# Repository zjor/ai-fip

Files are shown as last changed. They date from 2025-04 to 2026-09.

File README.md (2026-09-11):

# AI-FIP — AI-controlled Flywheel Inverted Pendulum

A flywheel (reaction wheel) inverted pendulum stabilized by a neural network trained with deep reinforcement learning. The network knows nothing about the physics or its own "body"; it learns by trial and error in simulation how to swing up and hold the upright position, and is then transferred to a real device.

## Overview

Digital soul aka AI-FIP (flywheel inverted pendulum) — обратный маятник, реакционное колесо. Само-стабилизирующаяся система, управляемая нейронной сетью. НС обучается в виртуальном пространстве, ничего не зная про устройство механизма и аналитические законы. Методом проб и ошибок (DRL) она должна научиться сама управлять двигателем и считывать угол, чтобы удерживать вертикальное положение.

### Motivation

Это модельная задача обучения НС, ничего не знающей о природе своего тела; потом она сможет обучиться управлять телом любой сложности. Для меня — проектирование механической системы, устройства, изучение текущего состояния нейронных сетей и механизмов обучения с подкреплением.

### Goal

Сделать устройство, из которого можно будет сделать DIY-kit, записать курс, классное промо-видео, сделать стенд на фестиваль света подобный Signal, походить по школам и институтам, показывать для вдохновления будущих поколений.

### Definition of done

- DIY-kit
- YouTube promo-video
- Участие в выставках (Signal, Maker Faire)
- Попробовать разные алгоритмы стабилизации
- Статья на Хабр и на аналогичном популярном зарубежном портале
- Прочитать >3 лекций для общественности
- Записать видео-интервью

## Process

- [Current tasks](docs/project/tasks.md) — single prioritized list of unfinished work
- [Roadmap](docs/project/roadmap.md) — phases, milestones and gates
- [Progress log](docs/project/log.md) — completed work and decisions
- [Project-management process](docs/project/README.md) — ownership and update rules

## Repository map

Organized by concept. `software/` runs on a laptop, `hardware/` runs on the device.

```
docs/                  project management, physics, hardware, DRL, references
software/
  sim/                 Python dynamics (RK4), LQR and PID regulators
  rl/                  Gymnasium environment, SB3/PPO training, ONNX export, trained models
  web/                 browser demo running the exported ONNX policy
hardware/
  firmware/
    esp32-stepper/     legacy 2025 build: ESP32 + MPU6050 + stepper
    moteus-host/       2026 build: Raspberry Pi + pi3hat + moteus driver (planned)
  cad/                 mechanics (planned)
  tools/mpu-renderer/  serial → WebSocket bridge for IMU angles
```

Trained policies are produced by `software/rl` into `software/rl/models/`. Consumers copy them at build or deploy time: the web build copies the ONNX file, the device firmware will do the same.

## Documentation

- [Documentation index](docs/README.md)
- [Physics: equations of motion and controllability](docs/physics/equations-of-motion.md)
- [Physics primer](docs/physics/primer.md)
- [Hardware and motor selection criteria](docs/hardware/hardware.md)
- [BLDC motor candidates](docs/hardware/motor-candidates.md)
- [Reference papers](docs/references/README.md)

## Notebooks

- [Regular pendulum damping simulation](https://colab.research.google.com/drive/1u6tl5SG2cvKg8DLndMQ9u2ieP07KyDuc#scrollTo=PbFrm5GsAxk4)
- [Stabilizing FIP with LQR](https://colab.research.google.com/drive/1kIb0vfg7HsaBy3xPXdWx9-hCGLleFcXF#scrollTo=zqa5uH2bmCwl)

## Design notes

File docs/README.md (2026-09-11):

# Documentation

Project knowledge and process, organized by concept.

## Project management

- [Current tasks](project/tasks.md) — single prioritized list of unfinished work
- [Roadmap](project/roadmap.md) — phases, milestones and gates
- [Progress log](project/log.md) — completed work and decisions
- [Process](project/README.md) — ownership and update rules

## Physics

- [Equations of motion and controllability](physics/equations-of-motion.md) — Euler-Lagrange equations of the free and actuated FIP, linearized state-space form, controllability matrix
- [Physics primer](physics/primer.md) — torque, K_t, K_v, K_m, thermal limits, momentum capacity, swing-up, FOC, cogging
- [Phase 0 feasibility check](physics/phase-0-feasibility.md) — reproducible torque, momentum, thermal, and sensor timing pre-check
- [Motor torque estimation](physics/torque-estimation.md) — measured parameters of the 2025 stepper build and the holding-torque estimate
- [Double inverted pendulum](physics/double-pendulum.md) — Euler-Lagrange derivation for the double pendulum

## Hardware

- [Hardware](hardware/hardware.md) — parameters, motor selection criteria, moteus driver integration, legacy stepper BOM
- [BLDC motor candidates](hardware/motor-candidates.md) — 15 motors evaluated, shortlist, buy list, final choice
- [CAD specification](hardware/cad-spec.md) — wheel, rod and table-clamp stand for OpenSCAD (`hardware/cad/`): frame, parameters, parts, BOM, mass model

## Deep reinforcement learning

- [DRL and simulation learning track](drl/README.md) — ordered curriculum, mastery criteria and resources
- [DRL outline](drl/outline.md) — problem statement, glossary, model-based vs model-free
- [Modern simulation and RL stack (2026)](drl/modern-simulation-and-rl-stack-2026.md) — simulator survey, Apple Silicon strategy, policy architecture, parallel training, and sim-to-real plan

## References

- [Reference papers](references/README.md)

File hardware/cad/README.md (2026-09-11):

# Mechanics — OpenSCAD

Parametric models of the reaction-wheel pendulum: wheel, rod, table-clamp
stand. Design and rationale: [docs/hardware/cad-spec.md](../../docs/hardware/cad-spec.md).
All dimensions live in `params.scad`.

## Build

```shell
make parts      # STLs into build/
make masses     # mass, centroid, inertia per part + pendulum mass model
make check      # interference check (must print "check: no interference")
make test       # geometry tests (python3 -m unittest, drives openscad)
openscad assembly.scad   # interactive view; set angle=... in the customizer
```

Requires OpenSCAD ≥ 2026.06 (manifold backend) and Python 3.12 (stdlib only).
`make check` passes when OpenSCAD reports an empty top-level object: the
intersection of the pendulum at 0/90/180/270° with the stand and table is empty.

## Parts and print orientation

| Part | File / `part` | Qty | Mass (rendered) | Orientation | Notes |
|---|---|---:|---:|---|---|
| wheel quadrant | `wheel.scad` / `quadrant` | 4 | 27.7 g | flat, rim down (144 × 144 mm) | 0.2 mm layers, 3 perimeters, 30 % infill |
| wheel hub plate | `wheel.scad` / `hub` | 1 | 16.1 g | flat, nut pockets down | 100 % infill |
| beam | `rod.scad` / `beam` | 1 | 63.9 g | web flat (X up), diagonal on the bed (230 × 20 mm) | 4 perimeters |
| motor flange | `rod.scad` / `flange` | 1 | 41.7 g | on edge (X up), brim (135 × 20 mm) | 4 perimeters, 50 % infill |
| stand | `stand.scad` / `stand` | 1 | 151.6 g | on its side (X up) (98 × 74 mm) | 5 perimeters, 40 % infill, PETG preferred |
| pad | `stand.scad` / `pad` | 1 | 3.4 g | flat | |

`wheel.scad / bolts` is not a print: it models the eight M6 tuning bolts
(66.7 g steel) for the mass model.

## Mass model (`make masses`, 2026-09-04)

| Part | Mass g | z CoM mm |
|---|---:|---:|
| wheel plastic (4 quadrants + hub) | 127.0 | 250 |
| wheel bolts (8× M6×20 + nut) | 66.7 | 250 |
| beam | 63.9 | 36 |
| motor flange | 41.7 | 228 |
| mj5208 | 193.0 | 250 |
| moteus r4.11 + screws | 19.2 | 250 |
| 4S pack | 120.0 | 0 |
| RPi 4 + pi3hat + standoffs (estimate) | 85.0 | 0 |
| axle, collars, clamp screws (estimate) | 60.0 | 0 |
| **total** | **776 g** | l_c = 146 mm |

G = 1.11 Nm, I_p = 0.029 kg m², I_w = 0.0027 kg m². These are the
`[design]` values in `software/sim/phase0.toml`.

## BOM (hardware)

| Item | Qty |
|---|---:|
| Steel shaft Ø8 × 120 mm | 1 |
| 608ZZ bearing 8 × 22 × 7 | 2 |
| Shaft collar Ø8 | 2 |
| M3 × 8 screws + nuts (rim laps 4, hub 8, clamp 2, lap joint 2) | 16 |
| M3 × 8 countersunk (rotor) | 3 |
| M3 × 10 (stator) | 4 |
| M2.5 × 12 screws + 20 mm standoffs (RPi / pi3hat) | 4 |
| M6 × 20 bolt + nut (tuning) | 8–12 |
| M8 × 60 thumb screw + M8 nut | 1 |
| Velcro strap 12 mm | 2 |
| mjbots mj5208, moteus r4.11, pi3hat, Raspberry Pi 4 | 1 each |
| 4S LiPo, 1000 mAh preferred (1000–1300 mAh), ≥40 A continuous / ≥45C at 1000 mAh, XT30 + JST-XH 5-pin, ≤75 × 35 × 25 mm, 100–130 g | 1 |

## Project tracking

CAD and mechanical work is tracked centrally as T-002, T-003 and T-008 in
[docs/project/tasks.md](../../docs/project/tasks.md).

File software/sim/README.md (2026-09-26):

# Simulation and classical control

Python model of the flywheel inverted pendulum: RK4 integration of the equations of motion (see [docs/physics](../../docs/physics/equations-of-motion.md)) with LQR, PID and neural-network control laws for comparison.

## Run

```shell
poetry install
poetry run app
poetry run phase0
poetry run phase0-swingup --sweep [--torque-limit 0.5]
poetry run phase0-control --pessimistic --sweep
poetry run python -m unittest discover -s tests
```

`phase0` runs the analytical hardware feasibility pre-check from
[`phase0.toml`](phase0.toml) using the moteus firmware conventions (Kt = 8.27/Kv,
voltage-circle torque-speed envelope). `phase0-swingup` simulates energy-pumping
swing-up plus LQR catch with that envelope and reports the required flywheel
momentum. `phase0-control` sweeps sample rate, delay and noise for the sampled LQR.
Mechanical low/nominal/high values are planning ranges, not measurements; the
report stays `NOT READY` until a CAD mass model exists. Results and decisions:
[docs/physics/phase-0-feasibility.md](../../docs/physics/phase-0-feasibility.md).

## Learning exercises

The numbered, self-contained [MuJoCo exercises](learning/mujoco/) are kept
separate from the `app` package while sharing this Poetry environment.

## Project tracking

Simulation work is tracked centrally in
[docs/project/tasks.md](../../docs/project/tasks.md), currently T-005.A–F and
T-009–T-012.
The associated curriculum and mastery criteria are in
[docs/drl/README.md](../../docs/drl/README.md).

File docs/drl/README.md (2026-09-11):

# DRL and simulation learning track

This is the curriculum for mastering deep reinforcement learning and 3D
simulation through AI-FIP. Project progress and current learning actions are
tracked only in [project/tasks.md](../project/tasks.md); the project phases
and gates live in [project/roadmap.md](../project/roadmap.md).

Principle: learn each concept by building, explaining, and measuring it in the
project. Do not start new policy training until the honest-simulation gate is
passed with a classical controller.

## Curriculum

- **MuJoCo foundations:** understand MJCF body trees, frames, hinge joints,
  inertial parameters, actuators, sensors, timestep, integration and the Python
  stepping/viewer API.
- **Validated 3D digital twin:** construct the two-DOF pendulum and reaction
  wheel from primitive dynamic geometry; reproduce the analytical RK4 model in
  passive, constant-torque and closed-loop trajectories; add CAD meshes only as
  visual geometry.
- **Honest classical-control baseline:** model the measured motor envelope,
  current limits, friction/cogging, sensor noise, sampling and delay; demonstrate
  swing-up, LQR catch, stabilization and wheel despinning.
- **RL foundations:** be able to explain and calculate MDP transitions,
  returns, value and action-value functions, Bellman equations, policy gradients,
  actor-critic, advantage estimation/GAE and PPO clipping.
- **Gymnasium environment design:** define deployable observations and
  actions, termination versus truncation, reward components, normalization,
  deterministic seeding and vectorized evaluation around the validated model.
- **PPO baseline:** train a small 2x64 policy and compare it with LQR using
  physical metrics: success rate, angle RMS, wheel speed, saturation, current,
  energy and recovery envelope—not reward alone.
- **Robustness and sim-to-real:** train and test across measured parameter
  ranges, use held-out worst-case evaluation, compare pure PPO with residual PPO,
  export the actor and measure end-to-end latency on the target host.

## Practical MuJoCo track

The self-contained exercises live in
[`software/sim/learning/mujoco/`](../../software/sim/learning/mujoco/). Their
progression is: viewer and static geometry; free-body contact; passive hinge
pendulum; Python stepping and logging; torque actuation and feedback; simple CAD
mesh import and mass-property comparison; and finally the two-DOF pendulum and
reaction wheel.

The final model starts with primitive dynamic geometry and explicit inertial
parameters. CAD meshes can then be compared against it and used where their
added geometric detail is useful. The track is complete when free fall, a fixed
torque pulse and the same LQR controller agree with the analytical RK4 model
within explicit error bounds or documented discrepancies.

## Resources

- [MuJoCo modeling guide](https://mujoco.readthedocs.io/en/latest/modeling.html)
- [MuJoCo Python bindings](https://mujoco.readthedocs.io/en/stable/python.html)
- [PPO explanation and equations](https://spinningup.openai.com/en/latest/algorithms/ppo.html)
- [Modern simulation and RL stack for this project](modern-simulation-and-rl-stack-2026.md)
- [DRL outline and glossary](outline.md)

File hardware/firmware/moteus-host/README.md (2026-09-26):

# moteus host controller

Control loop for the 2026 build: Raspberry Pi + pi3hat (CAN-FD, IMU) commanding a moteus driver with an mjbots mj5208 motor. Python, LQR first, then the ONNX policy from `software/rl/models/`.

See [docs/hardware/hardware.md → Driver: moteus](../../../docs/hardware/hardware.md) and [docs/project/roadmap.md](../../../docs/project/roadmap.md) Phase 3. Current work is tracked in [docs/project/tasks.md](../../../docs/project/tasks.md).

## Minute clock

`minute-clock` is a small bench exercise for learning position control. An arrow
attached to the motor advances 30 degrees every 5 seconds and completes one
revolution per minute. It runs continuously until `Ctrl-C`.

Use Python 3.12+ and the official [`moteus` Python
package](https://pypi.org/project/moteus/). From this directory:

```shell
poetry install
poetry run minute-clock --calibrate
```

With `--calibrate`, the controller first enters stop mode. Rotate the arrow to
12 o'clock by hand and press Enter. The program stores that absolute encoder
angle, modulo one revolution, in `.minute-clock-zero.json`. The file is local
device state and is ignored by Git.

On later runs, omit `--calibrate`. The program loads the stored zero, moves to
the nearest equivalent 12 o'clock position, waits until the arrow settles, and
then starts the five-second ticks. Recalibrate only if the arrow moves relative
to the rotor or if you intentionally want to redefine 12 o'clock.

The program assumes controller ID 1 and lets the `moteus` package auto-detect
the connected `fdcanusb`. Run it first with the motor securely mounted, the
arrow clear of people and objects, and a way to disconnect power immediately.
The initial limits are intentionally modest: 0.10 Nm, 0.25 rev/s and
0.50 rev/s².

Positive position may look clockwise or counterclockwise depending on the side
from which the arrow is viewed and the configured motor direction. If the first
tick goes the wrong way, press `Ctrl-C` and recalibrate with the other sign:

```shell
poetry run minute-clock --calibrate --clockwise-sign -1
```

The chosen clockwise sign is stored alongside the zero position.

Useful options:

```shell
poetry run minute-clock --help
poetry run minute-clock --id 2 --max-torque 0.05
```

The command is refreshed every 20 ms and uses a 100 ms watchdog. Normal exit,
`Ctrl-C`, and Python exceptions all send `set_stop()` before the process exits.
Cut power if the host or CAN adapter itself fails; software stopping is not an
emergency stop.

## Bench characterization

The T-005.A–F bench suite stores raw runs under the ignored `logs/bench/` directory.
Tracked safety and experiment defaults are in `bench.toml`; the measurement
design and later experiments are documented in
[`docs/hardware/motor-bench-spec.md`](../../../docs/hardware/motor-bench-spec.md).

Start with the stopped-state inspection. It does not command motion:

```shell
poetry run bench inspect
```

It records five seconds of telemetry plus the complete controller configuration
and firmware identity. Review the reported voltage, temperature, home state and
fault before continuing.

The first motion experiment performs two cycles of +30°, centre, −30°, centre
at the conservative limits in `bench.toml`:

```shell
poetry run bench position-step
```

The program prints the resolved motion limits and requires typing `MOVE` before
it enables position control. Both commands always attempt `set_stop()` on exit.
Each run contains `run.json`, `controller-config.txt`, `telemetry.csv` and
`events.csv`.

After position steps pass, the low-speed friction/cogging experiment stages at
the nearest endpoint of `[-0.5, +0.5]` rev, sweeps one full revolution to the
opposite endpoint, then returns over the same positions:

```shell
poetry run bench friction
```

It takes about 100 seconds of motion at 0.02 rev/s, caps torque at 0.05 Nm, and
requires typing `SWEEP`. The arrow needs unobstructed 360° clearance. Progress is
reported every five seconds, and experiment-specific hard limits stop motion if
speed exceeds 0.35 rev/s or displacement exceeds 1.10 revolutions. The velocity
margin permits the short stick-slip releases that this experiment measures; it
does not change the commanded 0.02 rev/s trajectory. Setup samples are retained
but excluded from the forward/reverse measurement phases. Preflight reads the
moteus position bounds and verifies that both fixed sweep endpoints fit with the
configured 0.02 rev endpoint margin.

For this bench fixture, the moteus bounds are `[-1.1, +1.1]`:

```text
conf set servopos.position_min -1.1
conf set servopos.position_max 1.1
conf write
```

Restart tview after changing configuration, then close it before running
`bench` so both programs do not compete for the CAN adapter. These remain hard
controller limits; the friction command also independently stops at 1.10 rev
displacement from its recorded origin.

Analyze a completed friction run offline with:

```shell
poetry run bench analyze logs/bench/<run-id>
```

The command leaves raw files unchanged and writes `summary.json`, a
100-position-bin `friction-map.csv`, and standalone SVG plots under `plots/`.
It uses matched forward/reverse medians to estimate direction-dependent
friction and position-periodic torque, and reports the dominant spatial
harmonics. All torque outputs remain labeled as moteus model-derived estimates,
not independent torque measurements.

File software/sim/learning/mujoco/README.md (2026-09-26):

# MuJoCo learning exercises

Small, cumulative exercises for learning MuJoCo while working toward
[T-001](../../../../docs/project/tasks.md). Each numbered directory is a runnable
snapshot and should remain understandable on its own.

Assets reused by multiple exercises live in [`assets/`](assets/). Exercise MJCF
files reference that directory with paths relative to their own location, so a
mesh has one canonical copy without depending on another numbered exercise.

Run commands from `software/sim` so every exercise uses this subproject's
Poetry environment.

## Exercises

1. [`01-static-box`](01-static-box/) — load a minimal MJCF scene and explore
   the interactive viewer and camera controls.
2. [`02-free-box`](02-free-box/) — add a dynamic body and observe gravity,
   contact, free-joint state, and mouse perturbations.
3. [`03-pendulum`](03-pendulum/) — constrain a compound body to one hinge and
   explore joint axes, local coordinates, inertia, and damping.
4. [`04-periodic-kicks`](04-periodic-kicks/) — step the model from Python and
   apply periodic torque pulses through a hinge motor actuator.
5. [`05-feedback-control`](05-feedback-control/) — close the loop with a
   saturated PD controller and reject external torque disturbances near upright.
6. [`06-cad-wheel`](06-cad-wheel/) — import the Onshape reaction-wheel STL and
   compare its compiled mass properties with a same-envelope solid cylinder.
7. [`07-flywheel-pendulum`](07-flywheel-pendulum/) — assemble the passive
   flywheel pendulum with a world-fixed support, motor housing and independently
   hinged CAD wheel, without actuation or contacts.
8. [`08-actuated-wheel`](08-actuated-wheel/) — swing up with energy shaping,
   catch and despin with LQR, then reject seeded random force pulses applied
   perpendicular to the rod; compare free fall, fixed-pulse and LQR trajectories
   with an analytical RK4 model.

Add later exercises as new numbered directories instead of rewriting earlier
ones. Keep observations that are specific to an exercise in that exercise's
README. Project task state remains in `docs/project/tasks.md`.

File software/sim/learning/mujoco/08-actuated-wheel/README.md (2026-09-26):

# 08 — Swing-up, LQR catch, and random kicks

This exercise controls the complete motion in one simulation. It starts just
beside the downward equilibrium, pumps pendulum energy through the reaction
wheel, hands over to LQR near upright, and then applies random external pushes
to test disturbance recovery. Torque is recalculated before every 2 ms MuJoCo
step.

From `software/sim`, run the deterministic 18-second scenario:

```shell
poetry run python learning/mujoco/08-actuated-wheel/check_model.py
```

On macOS, view it at half real-time speed:

```shell
poetry run mjpython learning/mujoco/08-actuated-wheel/view.py
```

Press **Backspace** to restart near the hanging position. Controller mode
changes and kick events are printed in the terminal.

Compare the same model against an analytical RK4 integrator:

```shell
poetry run python learning/mujoco/08-actuated-wheel/compare_rk4.py
```

## Viewer plots

Four synchronized plots are stacked from the rendering viewport's top-right:

1. requested control `u`, before torque limiting;
2. absolute wheel angular velocity;
3. actual motor torque after limiting;
4. wrapped rod angle in degrees, with zero at upright.

Their compact titles are `u`, `ω`, `τ`, and `θ`. Each panel is now composed from
two independent pixel-space components: a 54 px header and a chart body. The
header renders DejaVu Sans with 14 px left and top padding. The requested panel
size is 576 × 390 px and all panels shrink identically only when the viewport
cannot fit the stack.

The chart body uses a fixed 72 px scale gutter and fixed frame coordinates.
Only the mapping from telemetry values to pixels changes when the Y range
changes; header, gutter, frame width, and frame height do not move. Rendering
the panels directly as images avoids `MjvFigure`'s data-dependent tick layout.

All plots use a rolling time axis from −10 s to 0, where zero is the newest
sample. Each vertical range follows its visible signal and adds 20% of the data
span on both sides; a small minimum range keeps constant signals readable. Grid
lines are hidden. Resetting the simulation also clears all plot history.

## Ideal actuator

The wheel hinge has a direct-drive torque source limited to the current mj5208
peak-torque assumption:

```xml
<motor name="wheel-torque" joint="wheel-hinge" gear="1"
       ctrllimited="true" ctrlrange="-1.7 1.7"/>
```

This is not yet an electrical motor model: there is no torque-speed curve,
current loop, command delay, or battery model. During swing-up, software applies
a lower ±0.5 N·m cap to avoid needlessly accumulating wheel momentum.

## State and LQR

The reduced controller state is

```text
x = [pendulum angle, pendulum rate, absolute wheel rate]
```

The hinge reports wheel speed relative to the carrier, so

```text
absolute wheel rate = pivot rate + wheel-hinge rate
```

`controller.py` finite-differences MuJoCo's continuous accelerations around the
motionless upright equilibrium to obtain `A` and `B`. It solves the continuous
Riccati equation with the Phase 0 costs:

```text
Q = diag(120, 2, 0.015)
R = 0.8
u_lqr = clip(-K x, -1.7, +1.7)
```

Penalizing absolute wheel rate makes LQR despin the wheel instead of balancing
with steadily accumulating momentum. Relative wheel angle is omitted because
the axially symmetric wheel has no preferred rotor angle.

## Swing-up and catch

With angle zero at upright and ±π at hanging, the pendulum energy relative to
upright is

```text
E = 0.5 I theta_rate² + G (cos(theta) - 1)
```

The controller derives `I` and `G` from the compiled MuJoCo model. While energy
is below the upright target it commands

```text
u_swing = clip(-k (-E) theta_rate, -0.5, +0.5)
```

Motor torque acts oppositely on the carrier, hence the minus sign. The controller
switches to LQR inside a 30° catch cone when the energy error is within 5% of
the hanging-to-upright energy difference. If it leaves 45°, it falls back to
swing-up mode.

## Random perpendicular kicks

After the first LQR catch, `disturbance.py` schedules seeded random pushes every
2.5–3.5 seconds, following an initial 1.0–1.5 second delay. Each push lasts
40 ms and has a random sign and magnitude from 2–4 N.

The force is applied at the wheel centre with `mujoco.mj_applyFT`. Its world
direction is the pendulum body's local X axis, while the rod lies on local Z;
those axes remain perpendicular as the pendulum rotates. This models an actual
lateral poke rather than injecting torque through the motor actuator. Seed 7
makes checks and viewer resets reproducible.

## Analytical RK4 comparison

`rk4.py` uses the reduced state `x = [θ, θ̇, ω]`, where `ω` is absolute wheel
speed. For applied wheel torque `u`, carrier inertia `I`, axial wheel inertia
`J`, gravity coefficient `G`, pivot damping `b_p` and relative wheel-hinge
damping `b_w`, its equations are:

```text
τ_w = u − b_w (ω − θ̇)
θ̈ = (G sin θ − b_p θ̇ − τ_w) / I
ω̇ = τ_w / J
```

The constants come from the compiled `scene.xml` mass matrix, gravity bias at
90°, and joint damping. For the current scene they are `I = 0.028399817 kg·m²`,
`J = 0.001464308 kg·m²`, `G = 1.134974359 N·m`, `b_p = 0.0002 N·m·s/rad`, and
`b_w = 0.005 N·m·s/rad`. This avoids a second, drifting set of physical inputs
while keeping the differential equations and RK4 step independent of MuJoCo's
dynamics solver. Torque is held constant over each 2 ms step. LQR uses the same
gain but computes its own torque from each model's state, with ±1.7 N·m clipping.

`compare_rk4.py` checks free fall from 10° for 0.7 s, a +0.2 N·m pulse for
0.1 s from upright followed by 0.4 s of coasting, and LQR from 5° for 2 s.
The maximum trajectory errors must stay below these limits:

| MuJoCo integrator | Scenario | Angle | Pivot rate | Wheel rate | Torque |
|---|---|---:|---:|---:|---:|
| Euler (scene default) | Free fall | 0.8° | 0.02 rad/s | 0.05 rad/s | 0 N·m |
| Euler (scene default) | Fixed pulse | 0.2° | 0.02 rad/s | 0.05 rad/s | 0 N·m |
| Euler (scene default) | LQR | 0.2° | 0.02 rad/s | 0.2 rad/s | 0.02 N·m |
| RK4 | Each scenario | 0.00001° | 0.00001 rad/s | 0.00001 rad/s | 0.00001 N·m |

The Euler bounds cover integration error at the scene's 2 ms step. In the
current comparison, the largest Euler angle error is 0.68834° during free fall;
the largest LQR wheel-rate error is 0.15936 rad/s. Switching MuJoCo to RK4 for
the same checks reduces all printed differences below 0.00000001 in their
respective units. The runner executes both integrators and exits nonzero if a
bound is exceeded. Angle differences are wrapped to ±π before comparison. The
RK4 result checks the equations, parameter extraction, actuation signs and
state mapping; the Euler result bounds the numerical
discrepancy of the scene as normally run. Swing-up and kick recovery remain
separate scenarios for later honest-model validation.

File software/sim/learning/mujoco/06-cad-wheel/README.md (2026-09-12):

# 06 — CAD reaction wheel

This exercise imports a binary STL exported from Onshape, verifies its scale
and orientation, and compares its compiled inertia with a same-mass solid
cylinder occupying the same outer envelope.

The STL format does not store units. The source coordinates are millimetres,
so the MJCF mesh asset applies `scale="0.001 0.001 0.001"`. The wheel's axle is
the source X axis. The mesh is closed and centred at its origin. Its canonical
copy is [`../assets/wheel.stl`](../assets/wheel.stl), shared with later
exercises instead of duplicated in each directory.

From `software/sim`, inspect the compiled model without opening a GUI:

```shell
poetry run python learning/mujoco/06-cad-wheel/inspect_model.py
```

Open the scene with:

```shell
poetry run python learning/mujoco/06-cad-wheel/view.py
```

The scene keeps the wheel fixed and disables contacts. This separates mesh
import, scaling and rendering from joints and collision behavior. The next
exercise can reuse the mesh as visual geometry while giving the reaction wheel
a hinge and deliberately selected collision and inertial properties.

## Mass and inertia assumptions

The mesh geom uses a PLA density of 1250 kg/m³. MuJoCo computes exact volume
integrals over the closed mesh because the asset specifies `inertia="exact"`.
This is useful for checking the CAD export, but the physical model should
eventually use the measured mass and inertia of the printed wheel plus bolts,
rotor and fasteners.

The `polished-metal` material changes only rendering. In MuJoCo's classic
viewer, a cool-grey color with high `specular` and `shininess` produces the
metallic appearance; it does not change the geom's PLA density or inertia.

The comparison cylinder has the mesh's mass, outer radius and thickness. It is
not a collision approximation: a solid cylinder fills the wheel's holes and
therefore distributes mass differently. Mesh collision would likewise use a
convex representation rather than reproduce every opening, so the imported
mesh is visual-only in this exercise.

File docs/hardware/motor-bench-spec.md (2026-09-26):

# mj5208 + moteus r4.11 bench characterization

## 1. Purpose

This bench suite turns T-005.A–F into reproducible measurements for the Phase 0
feasibility model and the later honest MuJoCo actuator model. It is not a single
maximum-power test. Work progresses from low-energy checks to mechanically
contained tests, and every run preserves raw commands, responses, configuration
and operator notes.

The required outputs are:

- command-to-motion delay and position/velocity tracking;
- low-speed friction and cogging versus rotor position, before and after moteus
  anti-cogging compensation;
- an independently measured torque constant from a lever arm and scale/load
  cell;
- coast-down loss versus speed with a known attached inertia;
- reachable torque versus speed and bus voltage;
- continuous stall torque versus motor winding temperature;
- explicit uncertainty and provenance for every value transferred into the
  simulation.

## 2. Operator workflow

The suite will expose one `bench` command from
`hardware/firmware/moteus-host`:

```shell
poetry run bench inspect
poetry run bench position-step
poetry run bench friction
poetry run bench coast-down
poetry run bench torque-constant
poetry run bench torque-speed
poetry run bench thermal-hold
poetry run bench analyze logs/bench/<run-id>
```

Each motion command prints the resolved limits and setup requirements, performs
a stopped-state preflight, asks for explicit operator confirmation, records one
run directory, and sends `set_stop()` on normal exit, fault, timeout or
`Ctrl-C`. A physical power disconnect remains mandatory; software stop is not
an emergency stop.

The friction experiment stages at the nearer of −0.5 or +0.5 rev, then measures
one full mechanical revolution to the opposite endpoint and back. Thus both
directional datasets cover identical rotor positions within `[-0.5, +0.5]`;
setup data is retained under a separate phase. Preflight validates the captured
moteus `servopos.position_min/max`, rejects a starting position outside them,
and requires 0.02 rev clearance between each sweep endpoint and either finite
bound. The bench program never rewrites persistent controller configuration.

Tests are introduced in three safety tiers:

| Tier | Experiments | Mechanical requirement |
|---|---|---|
| A | `inspect`, `position-step`, very slow `friction` | Current desk stand; light arrow; clear workspace |
| B | `coast-down`, inertia/acceleration sweeps, moderate-speed tests | Balanced retained rotor/flywheel and a guard; no arrow |
| C | `torque-constant`, `torque-speed`, `thermal-hold` | Purpose-built restraint/load fixture, independent force or temperature instrumentation, supervised run |

The clock is not reused for Tier B or C: its arrow is unsuitable for meaningful
speed, torque or thermal characterization.

## 3. Telemetry record

The target acquisition rate is 200 Hz for motion tests and 20 Hz for slow
thermal tests. Every row in `telemetry.csv` contains values as received or sent;
derived quantities belong in analysis outputs.

### Host and run state

| Field | Unit | Purpose |
|---|---:|---|
| `sample` | count | Detect missing or duplicated rows |
| `host_time_s` | s | Monotonic time from the first command |
| `scheduled_time_s` | s | Intended sample time for jitter analysis |
| `request_time_s`, `response_time_s` | s | CAN round-trip and timing jitter |
| `experiment_phase` | text | Preflight, settle, sweep, coast, cooldown, etc. |

### Commanded values

| Field | Unit |
|---|---:|
| `command_mode` | text |
| `command_position_rev` | rev |
| `command_velocity_rev_s` | rev/s |
| `feedforward_torque_nm` | N·m |
| `maximum_torque_nm` | N·m |
| `velocity_limit_rev_s` | rev/s |
| `accel_limit_rev_s2` | rev/s² |
| `watchdog_timeout_s` | s |

Unused command fields are empty, not silently replaced with zero.

### moteus response

| Field | Unit | Notes |
|---|---:|---|
| `mode`, `fault` | enum | Always recorded; any fault ends motion |
| `position_rev` | rev | Output position |
| `velocity_rev_s` | rev/s | Output velocity |
| `torque_nm` | N·m | moteus estimate, not an independent torque sensor |
| `q_current_a`, `d_current_a` | A | Measured phase-current components |
| `bus_voltage_v` | V | Controller input voltage |
| `electrical_power_w` | W | Positive into motor, negative into DC bus |
| `controller_temperature_c` | °C | r4.11 board temperature |
| `motor_temperature_c` | °C | Valid only with a configured motor thermistor |
| `home_state`, `trajectory_complete` | enum/bool | Encoder reference and trajectory state |

The logger requests floating-point position, velocity and torque plus sufficient
resolution for current, voltage, power and temperature. The exact query format
is stored in run metadata.

### Independent and manual observations

`events.csv` records timestamped facts not supplied by moteus:

- applied force or load-cell reading and lever-arm length;
- external winding/case temperature and ambient temperature;
- physical stop, contact, noise or vibration;
- operator abort and reason;
- configuration changes such as enabling anti-cogging.

If an external sensor later gains a programmatic interface, its samples receive
their own raw file and clock description rather than being disguised as moteus
telemetry.

## 4. Run metadata and derived results

`run.json` is written before motion and finalized after stop. It records:

- run ID, wall-clock start/end and exact CLI invocation;
- experiment name and all resolved limits/setpoints;
- motor, controller, CAN adapter, supply and mechanical-fixture identifiers;
- arrow/flywheel/load configuration, mass and known inertia;
- ambient conditions, cooling state and external instruments;
- Python and `moteus` versions, Git revision and dirty state;
- controller ID, firmware information and query resolution;
- result (`completed`, `aborted`, `fault`, `timeout`) and reason.

`controller-config.txt` is a read-only configuration snapshot captured before
the run. This is essential because PID gains, motor `Kv`, current limits,
position scaling, anti-cogging and thermal settings change the meaning of the
telemetry.

Offline analysis writes `summary.json` and plots, never modifies raw files.
Typical derived signals are RPM, position/velocity error, angular acceleration,
mechanical power $\tau\omega$, estimated copper loss, latency percentiles,
temperature rise and fitted friction/cogging curves. The analysis must label
reported torque as model-derived and use external force data for the torque
constant result.

## 5. Repository and data layout

```text
hardware/firmware/moteus-host/
  pyproject.toml
  bench.toml                    tracked conservative defaults and stop limits
  moteus_host/
    clock.py
    bench/
      cli.py                    command selection and operator interaction
      servo.py                  moteus query format and command cycle
      recorder.py               run metadata, CSV and event writing
      safety.py                 preflight, limits, fault/timeout stop path
      experiments/
        inspect.py
        position_step.py
        friction.py
        coast_down.py
        torque_constant.py
        torque_speed.py
        thermal_hold.py
      analysis/
        summarize.py
        plots.py
  tests/
    test_clock.py
    bench/
  logs/                         ignored; never committed
    bench/
      20260920T143012Z_position-step/
        run.json
        controller-config.txt
        telemetry.csv
        events.csv
        summary.json            generated by `bench analyze`
        friction-map.csv        matched directional position bins
        plots/                  generated PNG/SVG files
```

CSV plus JSON is preferred initially: the data volume is small, files are easy
to inspect, and no dataframe dependency is required in the hardware control
path. A column/schema version in `run.json` allows a later Parquet export
without changing the raw acquisition format.

## 6. Experiment sequence and gates

1. **Inspect and idle baseline.** Confirm identity, firmware, home state, bus
   voltage, zero current, temperatures and configuration snapshot without
   motion.
2. **Position steps.** Reuse the safe clock-scale motion to validate timestamps,
   watchdog behavior, tracking, repeatability and latency.
3. **Slow bidirectional friction/cogging.** Traverse several revolutions in both
   directions at very low speed. Fit repeatable torque versus wrapped position
   and direction. Back up configuration before changing anti-cogging settings.
4. **Independent torque constant.** Use a measured lever arm and scale/load
   cell at several low currents in both directions. moteus-reported torque is a
   comparison channel, not the reference measurement.
5. **Coast-down and acceleration.** Only with a known, retained inertia and
   guard. Estimate velocity-dependent losses and check torque-to-acceleration.
6. **Torque-speed envelope.** Sweep only bus voltages and speeds relevant to
   the 12.0–16.8 V design range. A credible torque-at-speed result requires a
   known inertia or external load; an unloaded speed sweep alone measures only
   the no-load boundary.
7. **Thermal hold.** Requires a motor thermistor or external temperature probe
   and a restraint rated for the commanded torque. Increase current/torque in
   conservative plateaus with configured absolute temperature, temperature-rise,
   temperature-rate, board-temperature, voltage and time stop conditions.
8. **Publish.** Transfer fitted values with uncertainty and run IDs into
   `docs/physics/phase-0-feasibility.md` and `software/sim/phase0.toml`; keep raw
   logs local and uncommitted.

Tier B starts only after the retained rotating assembly and guard exist.
Tier C starts only after its fixture and independent instrumentation are
documented and checked.

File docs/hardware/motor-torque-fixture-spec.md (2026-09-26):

# MJ5208 static torque fixture

## 1. Purpose

This fixture independently measures the mj5208 torque constant for T-005.C. A
rigid lever attached to the rotor presses vertically on a compression scale
while moteus commands short Q-axis current plateaus. The scale is the force
reference; moteus-reported torque is recorded only for comparison.

The first test is deliberately limited to ±8 A and approximately ±0.20 Nm. It
does not characterize peak torque, continuous thermal torque or torque at speed.

## 2. Measurement principle

```text
                         motor axis
                             O
                             │
    left contact ●───────────┼───────────● right contact
                 <--- 100.0 mm --->
                                                ↓ force
                                          ┌───────────┐
                                          │   scale   │
                                          └───────────┘
```

Use a balanced crossbar with a contact point on each side. Put the scale under
the contact loaded by the commanded torque direction; move it to the other side
for the opposite direction. The force must be perpendicular to the lever.

For effective radius $r$ and zero-corrected scale reading $m$:

$$
\tau = m g r
$$

With $r = 0.1000$ m and the reading expressed in grams:

$$
\tau[\mathrm{N\,m}] = m[\mathrm{g}] \times 0.000980665
$$

The fitted model is:

$$
\tau = K_t I_q + b
$$

where $I_q$ is measured Q-axis current, not merely its requested value. The
slope is the independently measured torque constant. The intercept contains
scale preload, zero error, residual cogging and fixture bias.

## 3. Mechanical design

### 3.1 Lever

- balanced metal crossbar, nominally 200 mm between contact centerlines;
- effective radius from the motor axis to each force line: **100.0 mm**;
- measure each radius after assembly to ±0.2 mm or better;
- aluminium flat bar is preferred; a printed lever is not the measurement
  reference because creep and bending add avoidable error;
- rigid hub using the mj5208 rotor M3 pattern, with no angular play;
- an adjustable rounded metal contact at each end, such as an M4 screw with a
  ball or acorn end;
- bar horizontal at the measurement point, so the vertical scale force is
  perpendicular to the radius.

The effective radius is the perpendicular distance from the motor axis to the
vertical force line. It is not automatically the physical bar length if the bar
or contact is angled.

### 3.2 Load path

- bolt the motor stator bracket and scale base to the same stiff baseplate;
- do not hold the motor, lever or scale by hand;
- constrain the scale so it cannot slide sideways;
- include a secondary hard stop just beyond normal scale deflection;
- add a loose guard or restraint that catches the lever if contact is lost;
- leave the unloaded end of the crossbar clear.

The scale is a measurement instrument, not the only structural restraint.

### 3.3 Scale

The available compression scale is rated to 3 kg with 0.1 g display resolution.
At 100 mm its nominal torque increment is 0.0000981 Nm. This is more than
sufficient; calibration accuracy, repeatability, force alignment and lever
radius dominate the uncertainty.

Check the scale before use with at least two known masses spanning roughly
0.2–1.0 kg. Record displayed resolution, repeatability, auto-zero behavior,
auto-off behavior and whether the reading is stable under a constant load.

## 4. Range

| Scale reading | Torque at 100.0 mm |
|---:|---:|
| 10 g | 0.00981 Nm |
| 100 g | 0.0981 Nm |
| 200 g | 0.196 Nm |
| 500 g | 0.490 Nm |
| 1000 g | 0.981 Nm |
| 1733 g | 1.70 Nm |

The scale can nominally contain the published 1.7 Nm motor peak at this radius,
but scale capacity alone does not qualify the fixture for a peak-torque test.
The hub, bracket, baseplate, contact, restraint, supply and thermal limits would
all require a separate Tier-C review.

## 5. Initial test protocol

### 5.1 Preconditions

- crossbar and hub inspected and fasteners marked against loosening;
- motor stator, scale and hard stop fixed to the common baseplate;
- contact radius measured and recorded for each side;
- scale checked with known masses, zeroed and prevented from auto-off;
- no hands or loose objects in the lever envelope;
- physical power disconnect immediately accessible;
- controller stopped, fault 0, bus voltage and temperature in limits;
- software watchdog and unconditional `set_stop()` path verified with a fake
  controller before the physical run.

### 5.2 Current plateaus

Use commanded Q-current plateaus of:

```text
0, 1, 2, 4, 6, 8 A
```

Run positive and negative directions separately, placing the scale beneath the
appropriate compression contact. Use measured `q_current_a` in analysis. Start
with 2–3 second plateaus and stop between plateaus. Repeat every nonzero point
three times. Abort on motion, loss of contact, unstable load, unexpected noise,
fault, voltage violation, current violation or temperature violation.

At the planning value $K_t \approx 0.025$ Nm/A, 8 A should produce about 0.20
Nm or 204 g at 100 mm. Do not raise the current range merely because the scale
has unused capacity.

### 5.3 Manual scale readings

The first version uses manual readings. The host must continue refreshing the
watchdog while current is active; a blocking terminal prompt must never pause
motor commands. Prefer this sequence:

1. run a fixed-duration plateau while recording moteus telemetry;
2. give the operator an audible/terminal timing cue;
3. stop the controller;
4. enter the observed stable or held scale reading in grams;
5. record side, current sign, radius, repetition and operator note in
   `events.csv`.

A camera recording of the scale display is useful evidence when the scale lacks
a data interface.

## 6. Planned software

`poetry run bench torque-constant` will reuse the recorder and safety layer. It
must:

- require a fixture-specific confirmation phrase;
- command current directly rather than request torque from the configured motor
  model;
- keep D-axis current at zero;
- refresh a 100 ms watchdog throughout every plateau;
- enforce the tracked 8 A initial phase-current limit;
- record requested and measured Q/D current, position, velocity, reported
  torque, bus voltage, power, controller temperature, fault and timing;
- stop between plateaus and on normal exit, fault, timeout or `Ctrl-C`;
- record manually entered scale readings and the measured contact radius;
- refuse higher-current profiles until the fixture receives a separate review.

Offline analysis will calculate torque for every reading, fit $K_t$ and an
intercept for each direction, compare slopes, report residuals and uncertainty,
and compare physical torque with moteus-reported torque.

## 7. Uncertainty and acceptance

At minimum, propagate:

- scale calibration and repeatability;
- scale resolution;
- left/right effective-radius measurement;
- lever non-perpendicularity, using the measured sine correction if needed;
- contact-position repeatability;
- measured-current variation during the reading window;
- regression residuals and positive/negative slope disagreement.

Accept the initial result when:

- force is monotonic with measured current in both directions;
- repeated readings at each plateau agree within a declared tolerance;
- positive and negative fitted $|K_t|$ values agree within 5%, or the asymmetry
  is investigated;
- the fit includes at least four nonzero current magnitudes per direction;
- no fixture motion, controller fault or safety-limit violation occurred;
- raw telemetry, events, controller configuration, dimensions and scale checks
  are preserved with the run ID.

## 8. Safety boundary

The initial fixture is approved only for short plateaus up to 8 A. It is not yet
approved for the published 1.7 Nm peak, continuous stall/thermal testing or
rotating torque-speed work. Those tests require a reviewed restraint, motor
temperature instrumentation and, for rotating tests, a retained balanced rotor
and guard.

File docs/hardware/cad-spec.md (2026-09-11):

# CAD specification — wheel, rod, stand (OpenSCAD)

Status: approved design, 2026-09-04. Source of truth for `hardware/cad/`.
Dimensions here are defaults; `hardware/cad/params.scad` is the single place
they live in code. When the two disagree, fix the one that is wrong and say so
in [project/log.md](../project/log.md).

## 1. Purpose and inputs

Printable mechanics for the 2026 build: a reaction-wheel pendulum on a
table-edge stand, driven by an mjbots mj5208 + moteus r4.11, sensed by the IMU
on a pi3hat riding on the pendulum, powered by a 4S pack on the pivot axis.

Decisions this spec implements (see [project/log.md](../project/log.md), 04.09.2026):

| Decision | Value |
|---|---|
| Pivot topology | rotating 8 mm axle clamped in the rod, two 608 bearings in the stand |
| Stand | C-clamp on the desk edge, cantilever bearing arm, axle perpendicular to the edge |
| Fabrication | FDM, PLA/PETG 1.25 g/cm³, bed 220 × 220 mm, parts > bed are segmented |
| Wheel | Ø280, four identical quadrants + hub plate, printed rim provides most of the inertia, M6 bolts for tuning |
| Angle sensor | IMU on the pendulum; no encoder on the stand (axle end kept free for one) |
| Electronics on the pendulum | 4S pack and RPi + pi3hat centred on the axle |
| Targets from Phase 0 | I_w ≈ 0.003 kg·m², rod 250 mm axle-to-motor-axis, G within the 0.97–1.34 Nm planning range (section 5 estimates 1.19) |

Verified motor mounting data (mjbots product page and blog, 2026-09-04):
mj5208 Ø63 × 25 mm, 193 g; rotor 3× M3 on a Ø17 bolt circle plus 2× M3 at
12 mm spacing; stator 4× M3 at 25 mm spacing plus 3× M2.5 at 32 mm. The exact
hole geometry (square vs. circle, depth, shaft protrusion) is **to verify**
against the mjbots 2D drawing before the first motor-flange print; it is
isolated in one parameter block and one part for that reason.

## 2. Coordinate frame

Right-handed, millimetres.

- Origin: axle centre, on the rod's mid-plane.
- **Z** up along the rod when the pendulum is upright.
- **Y** along the axle, positive away from the table edge.
- **X** along the table edge.

The pendulum rotates about Y. The stand occupies Y < 0 (bearing arm) and
Y ≪ 0 (clamp on the table). The axle sits `axle_height` above the table top so
the bearing arm clears the surface; the table top is the box X ∈ ℝ,
Y ≤ −`axle_overhang`, Z ∈ [−`axle_height` − `table_thickness`, −`axle_height`].

## 3. Parameters (`params.scad`)

| Name | Default | Meaning |
|---|---:|---|
| `bed` | 220 | printable square, mm; parts longer than `bed·√2 − 15` are split |
| `rho_pla` | 1.25e-3 | g/mm³ |
| `rod_len` | 250 | axle axis to motor axis |
| `wheel_d` | 280 | rim outer diameter |
| `rim_radial` | 8 | rim radial thickness (sized for inertia per gram, not stiffness; 2026-09-04) |
| `rim_axial` | 8 | rim axial width |
| `spokes` | 8 | two per quadrant |
| `spoke_w`, `spoke_t` | 4, 8 | spoke section (tangential × axial) |
| `hub_d`, `hub_t` | 60, 5 | hub plate and quadrant flange |
| `pocket_n`, `pocket_bolt` | 16, M6 | tuning holes, every 22.5° starting at 11.25°, axial through the rim, plain (nut and head clamp the rim faces) |
| `motor_d`, `motor_len` | 63, 25 | mj5208 |
| `rotor_bc_d`, `rotor_n` | 17, 3 | rotor pattern, M3 |
| `stator_pitch`, `stator_n` | 25, 4 | stator pattern, M3, square — **to verify** |
| `axle_d`, `axle_len` | 8, 120 | steel shaft |
| `bearing` | 8 × 22 × 7 | 608 |
| `bearing_spacing` | 40 | between bearing centres |
| `axle_overhang` | 60 | table edge to rod mid-plane |
| `axle_height` | 30 | table top to axle centre |
| `table_thickness` | 18–40 | clamp range |
| `battery` | 75 × 35 × 25 | 4S 1000 mAh class, on the table side of the rod |
| `hat_holes` | 58 × 49, M2.5 | RPi/pi3hat pattern, on the outer side of the rod |
| `beam_w`, `beam_h`, `flange_t`, `web_t` | 20, 20, 3, 3 | rod I-beam section |
| `clearance` | 0.3 | print fit for lap joints and pockets |
| `M3`, `M2.5`, `M6`, `M8` | 3.4, 2.8, 6.4, 8.4 | through-hole diameters |

## 4. Parts

### 4.1 Wheel (`wheel.scad`)

Five prints: four identical **quadrants** and one **hub plate**.

- Quadrant: a 90° rim arc (r from `wheel_d/2 − rim_radial` to `wheel_d/2`,
  width `rim_axial`), two spokes at 22.5° and 67.5°, and a 90° sector of the
  hub flange (r ≤ `hub_d/2`, thickness `hub_t`). Rim ends carry a half-lap
  joint (5 mm long, half the rim width) with one M3 through-hole; flange
  sector has two M3 holes on a Ø45 circle matching the hub plate.
- Hub plate: Ø`hub_d` × `hub_t` disc with the rotor pattern (3× M3 on Ø17,
  countersunk from the motor side), a Ø10 centre bore for the rotor boss,
  and 8× M3 on Ø45 for the quadrants.
- Tuning holes: `pocket_n` axial through-holes Ø`M6` in the rim at
  r = `wheel_d/2 − rim_radial/2`, every 22.5° starting at 11.25° so no hole
  lands on a lap seam or a spoke; no recess (the M6 nut overhangs the 8 mm rim
  by 1 mm per side, which is harmless). Bolts are always fitted in
  diametrically opposite pairs; the standard fit is 8 bolts every 45°.
- Lightening: none beyond the spoke design; the quadrant's rim and spokes are
  already the minimum structure.

Estimated: rim 68 g, spokes 31 g, flanges + hub plate 34 g → **~135 g
plastic, I_w ≈ 0.0015 kg·m² empty**; each M6 × 20 bolt + nut (≈ 10 g) at
r = 136 mm adds ≈ 0.000185 kg·m². Eight bolts (80 g) reach 0.0030, so the
standard wheel is ≈ 215 g. The rim was deliberately thinned from 12 × 10 mm:
plastic at the rim gives 0.0185 kg·m² per kg, a bolt at the rim 0.0185 too,
but spokes and hub give almost nothing, so the structure is kept minimal and
the inertia is bought with bolts where it can be tuned.

The wheel bolts to the rotor. The rotor's second pattern (2× M3 at 12 mm) is
left unused.

### 4.2 Rod: beam (`rod.scad`, module `beam`)

One print, laid diagonally on the bed. From the axle clamp at Z = 0 to the
lap joint ending at Z = `rod_len − 60` (bed fit).

- Section: I-beam, `beam_w` × `beam_h`, flanges `flange_t`, web `web_t`.
- Web cutouts: elliptical holes, 8 × 30 mm, centred at Z = 65, 100, 135;
  none in the tray zone or near joints.
- Axle clamp at Z = 0: a split clamp block 30 × 30 × 20 mm around Ø`axle_d`,
  slot 1.5 mm, two M3 clamping screws across the slot. The axle is also
  cross-drilled and pinned optionally (hole provided, Ø2).
- Tray zone Z ∈ [−45, 45] (the battery is centred on the axle):
  - table side (−Y): a shelf 80 × 40 mm with two 12 mm strap slots for the
    4S pack; pack outer face at Y = −(beam_h/2 + 25).
  - outer side (+Y): four M2.5 bosses on the 58 × 49 HAT pattern, 6 mm high,
    HAT long axis along Z, bosses at Z = ±29 so the board is centred on the
    axle.
- Lap joint at the top: the beam ends in a half-thickness tongue 40 mm long
  with two M3 through-holes 25 mm apart, mating the flange plate's groove.

Estimated 60 g.

### 4.3 Rod: motor flange (`rod.scad`, module `motor_flange`)

One print. A plate Ø70 × 6 mm carrying the stator pattern (4× M3 on the
`stator_pitch` square, counterbored), a Ø12 centre hole for the rotor
shaft/magnet side, and a 40 mm groove continuing the I-beam down to overlap
the beam's tongue (two M3 through-holes). The motor sits on the +Y face; the
wheel therefore spins on the outer side, away from the table.

Estimated 25 g. Reprint this part alone once the stator pattern is verified.

### 4.4 Stand (`stand.scad`)

One print (two if `bed` forbids), PLA at ≥ 4 perimeters, solid where loaded.

- C-clamp: throat depth 60 mm, opening 18–40 mm, jaw 40 mm wide; the fixed
  jaw is the top, the moving jaw is an M8 thumb screw through a printed
  M8 nut pocket in the lower jaw, with a 25 mm pad. Clamp body wall 8 mm.
- Cantilever bearing arm: rises `axle_height` from the clamp's top jaw and
  extends along +Y so that the two 608 pockets (Ø22 +0.2, 7 deep, with a 1 mm
  shoulder and an inner Ø17 relief) sit at Y = −(`axle_overhang` − 10) − 40
  and Y = −(`axle_overhang` − 10), i.e. at −90 and −50 with the defaults. The
  arm is a 40 × 40 box beam with 6 mm walls and diagonal ribs, its underside
  ≥ 5 mm above the table top; the axle passes through both bearings with a
  printed spacer between and a shaft collar outboard of each bearing.
- The axle end at −Y protrudes 8 mm past the inner bearing and is left free
  (future encoder magnet).
- Clearance requirements: rod mid-plane at Y = 0 is `axle_overhang` from the
  table edge; the battery's outer face at Y = −35 leaves ≥ 20 mm to the edge;
  the wheel and motor are at Y > 0 and clear everything.

Estimated 180 g. Weight does not matter here; stiffness does.

### 4.5 Axle and hardware (BOM in `hardware/cad/README.md`)

| Item | Qty |
|---|---:|
| Steel shaft Ø8 × 120 mm (h6) | 1 |
| 608ZZ bearing 8 × 22 × 7 | 2 |
| Shaft collar Ø8 | 2 |
| M3 × 8 screws (wheel joints, clamp, lap joint) | 24 |
| M3 × 8 countersunk (rotor to hub plate) | 3 |
| M3 × 10 (stator to flange) | 4 |
| M2.5 × 12 + standoffs (RPi/pi3hat) | 4 |
| M6 × 20 bolt + nut (tuning) | 8–12 |
| M8 × 60 thumb screw + nut | 1 |
| Velcro strap 12 mm | 2 |

## 5. Mass model and feedback to Phase 0

`make masses` computes each printed part's volume, centroid and inertia from
its STL and combines them with catalogue hardware masses. Rendered on
2026-09-04 (`hardware/cad/README.md` has the per-part table):

| Part | Mass | z of CoM | Contribution to G (Nm) |
|---|---:|---:|---:|
| wheel plastic + 8 tuning bolts | 194 g | 250 | 0.48 |
| mj5208 + r4.11 + screws | 212 g | 250 | 0.52 |
| motor flange | 42 g | 228 | 0.09 |
| beam | 64 g | 36 | 0.02 |
| axle, collars, clamp screws (estimate) | 60 g | 0 | 0 |
| 4S pack | 120 g | 0 | 0 |
| RPi 4 + pi3hat + standoffs (estimate) | 85 g | 0 | 0 |
| **total** | **0.776 kg** | l_c = 0.146 m | **G = 1.11 Nm** |

I_p = 0.029 kg m² (beam as a slender rod, everything else as point masses),
I_w = 0.0027 kg m² with 8 bolts (10 bolts give 0.0030). This sits between the
Phase 0 nominal (0.97 Nm) and pessimistic (1.34 Nm) corners, where the r4.11
has ≥ 3.7× margin at 20° and passes torque-capped swing-up at every point. The
uncapped direct lift at 12 V reaches 71–79 % of no-load wheel speed at
I_w 0.0027, above the 70 % limit: fit 10 bolts (0.0030) or cap swing-up torque
at 0.5 Nm in software. Two levers if the printed parts
come out heavier: shorten `rod_len` (G ∝ rod length), or use an RPi Zero 2 W.
These numbers are the `[design]` block of `software/sim/phase0.toml`
(nominal, −10 % / +10 %); `poetry run phase0 && poetry run phase0-swingup
--sweep` must still pass after any change.

## 6. Build and checks (`Makefile`)

- `make parts`: renders `wheel_quadrant.stl`, `wheel_hub.stl`, `beam.stl`,
  `motor_flange.stl`, `stand.stl` headlessly
  (`openscad --backend=manifold -o <out> -D part="<name>" <file>`).
- `make masses`: renders each part and computes volume, mass, centroid and
  moment of inertia from the STL with `tools/stl_props.py`;
  `tools/mass_model.py` combines them with the hardware masses into m_t, l_c,
  I_p and I_w.
- `make check`: renders `check.scad`, which computes the intersection of the
  pendulum assembly at 0°, 90°, 180°, 270° with the stand and with the table
  box. The Makefile fails if the resulting STL contains any facet.
- `make view`: renders `assembly.stl` for visual inspection; the assembly
  file also shows the pendulum at a parametric angle.

Each part also fits the bed: `lib.scad` asserts the part's bounding box
against `bed` (diagonal allowed) at render time.

## 7. Files

```
hardware/cad/
  params.scad     all dimensions, materials, hardware sizes
  lib.scad        report(), screw holes, bed assertion, hex nut pocket
  wheel.scad      quadrant, hub_plate; part selector
  rod.scad        beam, motor_flange; part selector
  stand.scad      clamp + bearing arm
  assembly.scad   everything placed, pendulum angle parameter
  check.scad      interference checks
  Makefile        parts, masses, check, view
  README.md       how to build, BOM, print settings, project-task links
```

## 8. Out of scope

Wiring, the CAN cable routing on the rod, the power switch, a battery
charger port, cable strain relief, and an encoder seat. These are Phase 1
detailing after the first print reveals what is missing.

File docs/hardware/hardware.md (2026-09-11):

# Hardware

##### Parameters
| Name | Value | Units |
| --- | ----- | ----- |
| Plastic density | 1.25  | g/cm³ |
| Wheel mass | | |
| Wheel inertia | | |
| Pendulum mass | | |
| Pendulum inertia | | |
| Mass of equipment  | | |
| Mass of a motor | | |
| Motor torque | | |
| Pendulum length, L | 0.25  | m |
| Wheel radius, R | 0.125 | m |

## Motor selection criteria

*Approved 2026-08-10. Scope: desktop DIY-kit scale, onboard battery (3S–4S), direct-drive BLDC + FOC, motor budget ≤ €120. Parametric — numbers are current estimates (m_t ≈ 0.55 kg incl. battery, l_c ≈ 0.18 m); Phase 0 of the [roadmap](../project/roadmap.md) iterates them.*

### Operating regimes

Each regime produces a distinct constraint:

- **Balance hold** — near-zero speed, rapid small torque reversals. Stall regime: pure I²R heating with no airflow; cogging torque directly pollutes control.
- **Disturbance recovery** — peak torque at low speed; sets the max recoverable angle.
- **Swing-up** — sustained torque while the wheel spins up; back-EMF eats torque as speed grows. Sets speed headroom and momentum capacity — likely the binding constraint for low-Kv gimbal motors.

### Hard criteria (pass/fail)

| # | Criterion | Formula | First estimate |
|---|---|---|---|
| 1 | Peak torque | τ_peak ≥ k·m_t·g·l_c·sin θ_max, k = 1.5–2, θ_max = 20° | ≥ 0.5–0.65 Nm |
| 2 | Torque reachable at bus voltage | K_t·min(V_bus/R_ph, I_driver) ≥ τ_peak | kills most high-R gimbal motors — check per candidate |
| 3 | Momentum capacity | I_wheel·ω_noload ≥ H_swingup (from honest sim), ω_noload = K_v·V_bus | TBD in Phase 0 — likely binding |
| 4 | Thermal continuous torque | ≥ ~0.3·τ_peak sustained at stall, no airflow | ≥ ~0.2 Nm |
| 5 | Motor mass | ≤ 0.2 kg (feeds back into m_t) | 5208-class ok |
| 6 | Smoothness | low cogging (≤ a few % of τ_peak), FOC-friendly PMSM | gimbal-class winding |
| 7 | Encoder | integrated magnetic encoder or exposed rear shaft for diametric magnet | AS5048A / MT6701 |
| 8 | Mechanical | rotor flange/holes to mount the wheel; Ø40–60 mm | |
| 9 | Price / sourcing | ≤ €120, EU/Ali availability (kit replicability) | T-Motor GB, iPower GM |

### Optimization objective, ranked

1. **Specific torque τ/m_motor (Nm/kg)** — the feasibility lever: motor mass raises its own torque requirement.
2. **K_v sweet spot** — high enough for momentum capacity at 11–15 V, low enough that τ_peak fits the driver current limit. Roughly K_v 30–100, K_t 0.1–0.3 Nm/A, R_ph ≲ 6 Ω.
3. **Cogging + friction minimal** — control quality around zero speed.
4. **Price, then documented torque/speed curve** — the real advantage of the €120 class over AliExpress.

No composite score — rank candidates by specific torque among those passing all nine gates.

**Amendment 2026-08-10:** the I_driver = 5 A assumption (SimpleFOC-class boards) was dropped in favor of moteus-class drivers (20–100 A peak). With the current limit gone, gate 2 stops favoring high-K_t gimbal windings: for the same stator, K_t ∝ turns and R ∝ turns², so the winding-independent figure of merit is the **motor constant K_m = K_t/√R** (torque per √watt of copper loss), and the practical limits become driver current and thermal (I²R at stall), not bus voltage. This reopened low-K_t robot motors → decision: mjbots mj5208 + moteus (see [motor-candidates.md](motor-candidates.md)).

## Driver: moteus — интеграция (researched 2026-08-11)

**Компания:** mjbots Robotic Systems LLC — США, Cambridge, Massachusetts; основана в 2019 Josh Pieper. Прошивка и софт открыты (Apache 2.0, [github.com/mjbots/moteus](https://github.com/mjbots/moteus)). ⚠️ На сайте: "shipping holiday — new orders ship August 17, 2026".

**Интерфейс:** CAN-FD 5 Mbps (разъём JST PH-3). Два протокола: register protocol (команды управления: position/velocity/torque + телеметрия) и diagnostic protocol (конфигурация, консоль). Классический CAN не подходит — нужны CAN-FD кадры; при длинной/шумной шине BRS отключается → 1 Mbps.

**Языки/библиотеки (в репо `lib/`):** Python (`pip install moteus`, asyncio API: `Controller.set_position()/set_stop()/query()`, `make_*` + `transport.cycle()` для мультимоторных шин), C++, Rust. GUI: `pip install moteus-gui` → `tview` (телеметрия, плоты, конфиг, REPL).

**Подключение к хосту (варианты):**
1. **ПК (dev): [fdcanusb](https://mjbots.com/products/fdcanusb) / mjcanfd-usb-1x** — USB→CAN-FD адаптер, Linux/Win/mac. Python-библиотека находит его автоматически (`transport=None`).
2. **Raspberry Pi (боевой контур): [pi3hat](https://mjbots.com/products/mjbots-pi3hat-r4-5)** — шляпа с CAN-FD + IMU на борту (IMU пригодится для угла маятника!); контур управления ≥1 kHz, `pip install moteus-pi3hat`.
3. **MCU (ESP32/STM32):** ESP32 имеет только классический CAN (TWAI) — нужен внешний SPI-контроллер CAN-FD (MCP2518FD) либо STM32G4 с FDCAN. Сложнее; для старта не рекомендуется.

**Электрика (из [electrical-setup](https://github.com/mjbots/moteus/blob/main/docs/guides/electrical-setup.md)):** питание XT30, полярность не защищена; hot-plug запрещён (inrush в конденсаторы — подключить всё, потом подавать питание / использовать mjpower-ss); фазы A/B/C припаиваются в любом порядке; терминатор CAN на конце шины.

**Рекомендуемый стек для маятника:** mj5208 + **moteus r4.11** (решение 2026-09-04: c1 даёт лишь 0.50 Nm peak и 0.125 Nm continuous без обдува — не проходит 20° и continuous-gate; см. [phase-0-feasibility.md](../physics/phase-0-feasibility.md)) + Raspberry Pi с pi3hat (CAN-FD и IMU одним устройством) — Python-контур для LQR/NN; fdcanusb для настольной отладки и tview.

**Константы moteus (проверено по прошивке, 2026-09-04):** K_t = 8.27/Kv (не 60/(2π·Kv)); фазное напряжение ограничено ≈0.4·V_bus, поэтому холостая скорость ≈ 0.7·Kv·V_bus (mj5208 при 12 V: 2740 rpm). Питание: 4S LiPo на оси вращения маятника.

### Battery requirement

Обычный **4S LiPo**: 14.8 V nominal / 16.8 V full, 1000–1300 mAh, разряд не менее 40 A continuous (для 1000 mAh — рейтинг ≥45C), силовой разъём XT30 и балансировочный JST-XH 5-pin. Ограничения CAD: не более 75 × 35 × 25 mm, целевая масса 100–130 g; предпочтительный вариант — 1000 mAh. Нужен 4S balance charger со storage mode. При торможении moteus возвращает энергию в DC bus, поэтому рекуперативные тесты нельзя начинать с полностью заряженной батареей.

## Legacy — 2025 stepper plan

##### Stepper motor torque
Considering [Nema 17](https://www.gme.cz/v/1500760/nema-17-dc-motor-krokovy-5v-2a-pro-tiskarny)
Current: <2A
Static torque: ~0.2...0.4 Nm (0,48Nm)
Dimensions: 42,3 x 42,3 x 39,8 mm
Mass: 0.22 ... 0.5 (depending on the model)
`Model: 17HS4401`
`1.7A, 0.42Nm`

###### BOM
| Name | Qty | Price | URL | Description |
| --- | --- | ----- | --- | --- |
| Bearing housing | 3 | | [ali](https://www.aliexpress.com/item/4000909587517.html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) | Used for holding a shaft |
| ESP32 DevkitC | 1 | | | |
| A4988 | 1 | | [hookup instruction](https://lastminuteengineers.com/a4988-stepper-motor-driver-arduino-tutorial/) | Stepper motor driver |
| L7805CV | 1 | | [mouser.com](https://cz.mouser.com/ProductDetail/STMicroelectronics/L7805CV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) | 5V voltage regulator |
| MPU9250 | 1 | | | Accel unit |

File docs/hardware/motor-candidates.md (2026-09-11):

# BLDC motor candidates

Researched 2026-08-10 against the [selection criteria](hardware.md#motor-selection-criteria) (15 motors evaluated from 22 scouted; sources: manufacturer datasheets, shop listings, SimpleFOC community builds).

**Method note:** reachable torque computed as τ = K_t · min(V_bus / R_terminal, 5 A) using **terminal (line-to-line) resistance** — two phases conduct, so per-phase R understates the limit ~2×. Several manufacturer "peak torque" claims cross-check against this formula (GL40 KV70: 0.15 × 3.29 A = 0.49 ≈ published 0.5 Nm peak).

## Verdict table (ranked)

| Motor | K_t, Nm/A | R_ll, Ω | τ @ 4S, Nm | ω_nl @ 4S, rpm | Mass, g | Ø, mm | Price EU | Encoder | Verdict |
|---|---|---|---|---|---|---|---|---|---|
| **CubeMars GL40 KV70** | 0.15 | 4.5 | **0.49** | 940 | 107 | 46.5 | €85 / €110 w-enc | factory variant | **Shortlist #1** — only full-caps pass, but τ ceiling = the floor |
| **iPower GM5208-24** | ~0.40 (derived) | 13.7 (11.1 meas.) | 0.43–0.60 | ~330 | 204 | 59.5 | €52 | add AS5048A in bore | **Shortlist #2** — cheap; swing-up momentum risk (Kv≈21) |
| **CubeMars G60 KV55** | 0.205 | 1.2 | **1.03** (5 A cap) | 814 | 226 | 69 | €132 | encoder bundle avail | **Stretch** — best performer; breaks mass/Ø/price caps ~10–15% |
| CubeMars GL60 KV25 | 0.45 | 5.5 | 1.21 | 318 | 230 | 69 | €132 | bundle avail | Stretch — big torque, low speed ceiling (momentum risk) |
| CubeMars GL40 II KV82.5 | 0.11 | 3.0 | 0.54 | 1221 | 125 | 46.1 | €154 | integrated 14-bit | Over budget; integrated CAN driver, not for external FOC |
| CubeMars GL60 II KV28 | 0.34 | 5.8 | 0.87 | 414 | 276 | 70.5 | €185 | none | Fail: mass+price (best-in-class cogging 1.5 cN·m) |
| iPower GM4108H-120T | ~0.1 (load spec) | 11.1 | ~0.2 | ~400 | 124 | 47 | €40 | AS5048A variant | Fail: torque — canonical SimpleFOC pendulum motor, too weak for our m·g·l |
| iPower GM6208-150T | ~0.87 (derived) | 32 | 0.40 | 163 | 249 | 69.5 | €85 w-enc | AS5048A variant | Fail: torque at 4S + size |
| Maxon EC 45 flat 60W (591477) | 0.036 | 0.94 | 0.18 (5 A cap) | 3922 | 113 | 43.5 | ~€150+? | Halls | Fail: needs ~26 A for its 0.9 Nm stall — wrong class for 5 A/4S |
| Eaglepower LA8308 90KV | 0.106 | 0.186 (unclear) | 0.53 | 1332 | 336 | 92 | €60 | none | Fail: 336 g / Ø92 blow the envelope |
| GBM2804H-100T / MKS YT2804 | ~0.064 | 10 | ~0.08 | 2220 | 50 | 35 | €16 | AS5600 integrated | Fail: torque ~6× short — light stick-pendulums only |
| MotorGo 3506 | unpublished | 9.5 (phase) | ~0.1–0.15 est | ? | 75 | 40 | €28 | magnet built-in | Fail: torque; camera-gimbal class |
| Nidec 24H677 | n/a (integrated driver) | n/a | 0.025 rated | n/a | ? | ? | €6 | FG speed only | Fail: no FOC access, 20× under torque floor — remrc-cube baseline only |

GL40 KV70 listed twice by scouts (two variants of same motor) — merged above. 4S numbers assume 14.8 V and a ≥5 A FOC driver.

## Shortlist notes

### 1. CubeMars GL40 KV70 — the in-budget pick
- Rated 0.25 Nm / peak 0.5 Nm @ 3.3 A; K_v–K_t self-consistent (63.5 rpm/V ↔ 0.15 Nm/A). 14 pole pairs, IP45, low-cogging gimbal winding, 8 mm hollow shaft.
- **On 3S only ~0.37 Nm → must run 4S.** Even then τ_max ≈ 0.5 Nm sits exactly at the criteria floor (k=1.5, θ_max=20°) — Phase 0 must confirm with real m_t·l_c whether the margin holds, or θ_max shrinks to ~15°.
- Its 107 g helps its own cause: lightest of the passing motors, lowers m_t.
- Encoder variant sold (model/IC undisclosed — verify interface before buying); base variant takes a diametric magnet in the 8 mm bore.
- Wheel mount: 4×M3 rotor-side per reseller; bolt circle unpublished — **check CubeMars STEP/2D drawing before designing the flywheel**.
- EU: OpenELAB Munich €84.65 / €109.95 w-encoder. Sources: [cubemars.com](https://www.cubemars.com/product/gl40-kv70-gimbal-motor.html), [store.cubemars.com](https://store.cubemars.com/products/gl40-kv70), [OpenELAB](https://openelab.io/products/cubemars-gl40-kv70-bldc-gimbal)

### 2. iPower GM5208-24 — the cheap proven-ish option
- K_t ~0.40–0.46 Nm/A **derived from Kv, not published**; SimpleFOC community measured lower R than spec (5.57 Ω used as phase value in their build) → τ @ 4S realistically 0.5–0.6 Nm.
- 204 g — exactly at the mass cap; Kv ≈ 21 → ω_nl @ 4S only ~330 rpm → smallest momentum ceiling of the shortlist; swing-up feasibility must be checked in Phase 0 sim first.
- A SimpleFOC user ran FOC current mode on it but called torque "unsatisfying" at a 1.2 A current limit — our 5 A budget is 4× that, so not disqualifying.
- No encoder; standard fix is AS5048A + diametric magnet on a plug in the 12.6 mm bore.
- EU: iflight-rc.eu €51.90 in stock. Sources: [iflight-rc.eu](https://iflight-rc.eu/en/products/ipower-gm5208-24-gimbal-motor), [SimpleFOC thread](https://community.simplefoc.com/t/optimizing-the-capabilities-of-ipower-gm5208-with-foc-current/2068)

### 3. CubeMars G60 KV55 — the stretch pick
- R_ll only 1.2 Ω → driver-limited: full 5 A × 0.205 = **1.03 Nm even on 3S** — 2× margin over the floor, and ω_nl @ 4S ≈ 814 rpm gives the best torque×momentum combination of the list.
- Costs the envelope: 226 g (+13% over cap), Ø69 mm, €132 (+10% over budget). The extra 120 g of motor raises required torque by ~0.1–0.15 Nm — still ~2× margin. If Phase 0 shows GL40's 0.5 Nm is not enough, this is the answer.
- Naming trap: store.cubemars.com "G60 KV55" page shows 472 g / Ø77 — that's an older/larger variant or shipping weight; series table + OpenELAB say 226 g. Verify at order time.
- EU: OpenELAB €131.95. Sources: [cubemars.com G60](https://www.cubemars.com/goods-955-G60.html), [OpenELAB](https://openelab.io/products/cubemars-g60-kv25-kv55-bldc)

## Buy list — top 7 (researched 2026-08-10)

Torque floor relaxed to **≥ 0.45 Nm @ 4S** after the battery-at-pivot decision (see log). τ@4S = K_t·min(14.8/R_ll, 5 A). Prices approximate, EUR, before shipping unless noted. Second sweep added 8 new candidates from SteadyWin / MyActuator (LK-TECH); all verified against manufacturer datasheets.

**Motors #6–7 are integrated-driver servos**: factory FOC driver + encoder onboard, commanded over CAN/RS485 — no SimpleFOC stage to build, but our own FOC code is bypassed. Architecture decision for Phase 1.

| # | Motor | τ@4S, Nm | ω_nl@4S, rpm | Mass, g | Encoder | Best buy | Price |
|---|---|---|---|---|---|---|---|
| 1 | CubeMars GL40 KV70 (w/ encoder) | 0.49 | 940 | 107 | factory (type undisclosed) | [OpenELAB EU — in stock](https://openelab.io/products/cubemars-gl40-kv70-bldc-gimbal) | €109.95 (+€19.95 ship); base €84.65; [CubeMars CN $97.99](https://store.cubemars.com/products/gl40-kv70) |
| 2 | iPower GM5208-24 | 0.5–0.6 | ~330 | 204 | none → AS5048A in bore | [iFlight EU (Austria) — in stock](https://iflight-rc.eu/en-us/products/ipower-gm5208-24-gimbal-motor) | €51.90; [iFlight CN $42.99](https://shop.iflight.com/ipower-motor-gm5208-24-brushless-gimbal-motor-pro1347) |
| 3 | CubeMars G60 KV55 | 1.03 (5 A cap) | 814 | 226 | none | [OpenELAB EU — in stock](https://openelab.io/products/cubemars-g60-kv25-kv55-bldc) | €131.95 (+€19.95); [CubeMars CN $108.99](https://store.cubemars.com/products/g60) — confirm KV55/226 g variant, store header wrongly says 472 g |
| 4 | SteadyWin GB6010-11 (w/ AS5048A) | 0.68–0.88 | ~237 | 241 (270 w-enc) | factory AS5048A or AS5600 | [SteadyWin CN — in stock](https://steadywin-motor.com/products/small-brushless-servo-motor-hollow-flat-gimbal-servo-drone-gimbal-camera-motor-8) | $39.50 w-enc (~€36); [AIFITLAB $36](https://aifitlab.com/products/steadywin-gb6010-motor) |
| 5 | CubeMars GL60 KV25 | 1.21 | 318 | 230 | optional variant | [DigiKey — 18 pcs, ~3 days](https://www.digikey.com/en/products/detail/cubemars/GL-60/16705299) | $108.99; [Oz Robotics w-enc $138.99](https://ozrobotics.com/shop/cubemars-gl60-kv25-bldc-gimbal-motor-with-encoder/); OpenELAB sold out |
| 6 | MyActuator RMD-L-5015 35T CAN (= LK-TECH MF5015 V2) | 0.82 | 636 (datasheet Kv 43; SMC title says 16KV — verify winding) | 174 | 14-bit integrated + CAN driver | [SMC Powers CN — in stock](https://shop.smc-powers.com/MF5015-CAN-16KV.html) | $84 (~€72); [RobotShop EU — restocking](https://eu.robotshop.com/products/myactuator-rmd-l-5015-35t-brushless-dc-motor-can); [datasheet](https://www.myactuator.com/l-5015-details) |
| 7 | MyActuator RMD-L-4015 20T CAN | 0.52 | 932 | 120 | 18-bit integrated + CAN driver | [SMC Powers CN — in stock](https://shop.smc-powers.com/MF4015-CAN-V2.html) | $77.50 (~€67) — confirm 20T winding with seller; [RCDrone $109 — sold out](https://rcdrone.top/products/myactuator-l-4015-20t-direct-drive-servo-motor-24v-0-49n-m-peak-torque-18-bit-encoder-can-rs485-for-robotics-and-drones) |

### Late addition — the winner: mjbots mj5208 + moteus (2026-08-10)

Dropping the SimpleFOC/5 A driver assumption reopened the low-K_t/high-current class ([details in log](../project/log.md)):

| Motor | K_t, Nm/A | τ peak | ω_nl@4S | Mass | Price | Buy |
|---|---|---|---|---|---|---|
| **mjbots mj5208** (Kv 330) | 0.025 (moteus 8.27/Kv; 0.027 at measured Kv 304) | 0.50 Nm w/ moteus-c1 (20 A); **1.7 Nm** w/ r4.11 (62–68 A) | 2740 rpm @ 12 V, 3380 @ 14.8 V under moteus (voltage circle) | 193 g | $74 (657 in stock) | [mjbots.com](https://mjbots.com/products/mj5208) |

*Corrected 2026-09-04: K_t and no-load speed now follow the moteus firmware conventions; the earlier 0.029 Nm/A, 0.58 Nm and 4900 rpm were the hobby formulas. Measured R_ph 0.047 Ω, L 28.6 µH, 14 poles. Driver decision: r4.11 — see [phase-0-feasibility.md](../physics/phase-0-feasibility.md).*

Pair with [moteus-c1](https://mjbots.com/products/moteus-c1) ($69, 20 A peak / 5 A cont bare, onboard encoder, CAN-FD, 8.9 g) or [moteus r4.11](https://mjbots.com/products/moteus-r4-11) ($94, 100 A peak, 12/32 A cont). Devkit-matched pair: board mounts over the rotor's rear diametric magnet. Bundle ≈ $143 — same as GL40+driver, with 1.2–3.5× the torque and no momentum ceiling. Caveats: US shipping + ~25–30% CZ VAT/duty; Ø63 mm; cogging character unverified (not a gimbal winding — check mjbots anti-cogging before ordering). GL40 KV70 stays as EU-stock fallback.

Honorable mentions (pass torque, fail mass/price): SteadyWin [DD7010-2](https://shop.smc-powers.com/DD7010-2-RS485-CAN.html) (1.10 Nm, 570 rpm, 261 g, $81.80 — don't confuse with -11 variant), LKMTECH [MHF6015-V3](http://shop.smc-powers.com/MHF6015-RS485.html) (1.30 Nm, 252 g, $135), CubeMars GL60 II KV28 (€144+, 276 g).

**Swing-up note:** motors with ω_nl ≲ 350 rpm (#2, #4, #5) have a small momentum ceiling — treat as balance-first unless Phase 0 shows a heavy rim closes the gap. #1, #3, #6, #7 have real speed headroom.

**Buying caveats:** SMC Powers (LK-TECH/MyActuator factory outlet) has an expired TLS certificate — content verified, order with that caveat or prefer RobotShop EU when restocked. AliExpress listings exist for most of these but pages didn't render for verification.

## Implications for Phase 0

1. **4S is effectively mandatory** — every shortlist motor loses 25% torque on 3S and GL40 drops below the floor.
2. **The market has a gap exactly at our spec**: in-budget gimbal motors top out at ~0.5 Nm reachable. Phase 0 feasibility math (real m_t, l_c) decides between "GL40 is enough", "pay/weigh up for G60 KV55", or "shrink the pendulum".
3. **Momentum capacity check** (criterion 3) is now concrete: compute H_swingup and compare against I_wheel × ω_nl for GL40 (940 rpm) vs GM5208 (330 rpm) — likely disqualifies GM5208 for swing-up.
4. Driver must deliver ≥5 A FOC (rules out SimpleFOC Shield v1-class 2 A boards; B-G431B-ESC1 or SimpleFOC PowerShield class needed) — feeds the Phase 1 driver decision.

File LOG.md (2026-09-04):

# Log

**04.09.2026 (4) — заказ mjbots: план и открытые вопросы на следующую сессию**
- **Рекомендация: заказывать мотор + драйвер сейчас.** Roadmap Phase 2 формально запрещает покупку железа до прохождения честной симуляции, но sampled-LQR с шумом, задержкой и реальной огибающей момент/скорость уже проходит (`phase0-control`), а два оставшихся входа Phase 2 — тепловой предел mj5208 и cogging — измеряются только на реальном моторе. Трактовка: kit = измерительный инструмент для закрытия Phase 0/2, а не прыжок через gate. **Печать механики — держать** до проверки паттерна статора по чертежу mjbots
- **Что заказывать** (цены с сайта mjbots, 04.09.2026):
  - [moteus r4.11 developer kit](https://mjbots.com/products/moteus-r4-11-developer-kit) — $219: mj5208 + r4.11 + кронштейн контроллер→мотор + БП 24 V 5 A + mjcanfd-usb-1x + STM32-программатор + разъёмы XT30/CAN + магнит энкодера. Отдельно мотор ($74) + r4.11 ($94) = $168 без кабелей, кронштейна и USB-CAN — kit выгоднее
  - [pi3hat r4.5](https://mjbots.com/products/mjbots-pi3hat-r4-5) — $149: IMU 1 kHz + 5× CAN-FD, хост для маятника. **Только для Raspberry Pi 4B / 3B+, Pi 5 НЕ поддерживается.** Для стендовых тестов не нужен (хватает USB-CAN из kit)
  - Итого $368 + доставка + ~25–30 % НДС/пошлина CZ ≈ €420–450 (оценка, не котировка)
- **Не блокирует заказ:** cogging — в moteus есть компенсация с прошивки 2022-07-11 (правки в 2024-05-20, прошивка 1.0.0 — май 2026), эффективность на mj5208 измерить на стенде; ток батареи — 1.7 Nm ≈ 65 A фазного тока, но на стопе это ~300 W → ~20 A от 4S, пакета 1000 mAh 30C достаточно
- **Вопросы, решить в следующей сессии:**
  1. Есть ли Raspberry Pi 4B или 3B+? Если только Pi 5 — pi3hat отложить, хост выбрать позже (варианты: RPi 4 + pi3hat; или другой хост + внешний IMU/энкодер)
  2. Заказывать pi3hat вместе с kit (одна доставка/растаможка) или отдельно после стендовых тестов?
  3. Согласен ли с трактовкой roadmap выше (kit до Phase 2 gate)? Если да — отметить в ROADMAP Phase 1 строку мотора как «заказано» при размещении заказа
  4. Паттерн статора mj5208: открыть 2D-чертёж с страницы продукта (Google Drive), проставить `stator_pitch`/геометрию в `hardware/cad/params.scad`, перепечатать только `motor_flange`
  5. Подстройка инерции: 8 болтов M6 (I_w 0.0027) + программный лимит момента при swing-up ≤0.5 Nm, или 10 болтов (0.0030) без лимита
- **Не из mjbots:** 4S LiPo 1000 mAh ≥30C, RPi 4B, вал Ø8×120, 2× 608ZZ, 2 стопорных кольца Ø8, метизы M3/M2.5/M6/M8 — см. BOM в [hardware/cad/README.md](hardware/cad/README.md)

**04.09.2026 (3)**
- **CAD-спецификация утверждена** ([cad-spec.md](docs/hardware/cad-spec.md)): вращающаяся ось Ø8 в двух 608-подшипниках стойки (A), стойка — струбцина на край стола с консольной подшипниковой балкой (C), ось перпендикулярна краю; угол — IMU pi3hat на маятнике; батарея 4S и RPi на оси; FDM, стол 220 мм
- колесо Ø280 из 4 одинаковых сегментов + ступица; обод 8×8 мм, 8 спиц 4×8, 16 отверстий под болты M6 для подстройки инерции (обод тонкий намеренно: пластик на ободе и болт на ободе дают одинаковую инерцию на грамм, спицы и ступица — почти ничего). По рендеру: пластик 127 g, I_w 0.0027 kg·m² с 8 болтами (0.0030 с 10)
- OpenSCAD-модели в `hardware/cad/` (`make parts|masses|check|test`): `stl_props.py` считает объём/центроид/инерцию из STL (проверено на кубе и цилиндре), 20 тестов на массы, габариты и посадку на стол печати, проверка пересечений маятника со стойкой и столом на 0/90/180/270°
- массовая модель из CAD → `phase0.toml`: m_t 0.776 kg, l_c 0.146 m, G 1.11 Nm, I_p 0.029, I_w 0.0027 (между nominal и pessimistic Phase 0). Peak/continuous и swing-up с ограничением ≤0.5 Nm проходят (24/24); прямой подъём на 1.7 Nm при 12 V раскручивает колесо до 71–79 % холостой скорости при I_w 0.0027 → 10 болтов (0.0030) или программный лимит момента. Тест `test_nominal_gravity_coefficient…` в `software/sim` переведён на CAD-значения
- открыто перед печатью: паттерн статора mj5208 (принят квадрат 25 мм, проверить по чертежу mjbots), массы RPi+pi3hat и осевой фурнитуры — оценки

**04.09.2026 (3)**
- **решение: обучение будет выполняться на Apple Silicon**; CUDA-only стек не является допустимой локальной зависимостью
- сохранён обзор современного стека симуляции и DRL → [modern-simulation-and-rl-stack-2026.md](docs/drl/modern-simulation-and-rl-stack-2026.md)
- основная рекомендация: сохранить аналитический RK4 как проверяемый oracle, построить честный 3D digital twin в MuJoCo, сначала проверить CPU MuJoCo + Gymnasium/PPO; MJX-JAX CPU/experimental Metal и Genesis Metal сравнить отдельным benchmark до выбора ускоренного backend
- нейросетевая гипотеза: маленький actor MLP 2x64, затем frame stacking/GRU только при необходимости; asymmetric critic с simulator-only параметрами; сравнить LQR+energy shaping, pure PPO и residual PPO

**04.09.2026 (2)**
- **решения:** swing-up обязателен; устройство должно держать «тычок пальцем» (θ_target = 10°, preferred 20°), сильнее — падение, флип и раскачка; механика проектируется с нуля; батарея 4S на движущейся части
- **решение: драйвер = moteus r4.11** ($94, 100 A peak / 12 A cont, 14.2 g). c1 проходит только peak-gate на 10° (2.2×), на 20° — 1.09× FAIL, continuous 0.125 Nm FAIL без обдува. r4.11: 7.3× / 3.7×, continuous 0.30 Nm, ограничен уже мотором (1.7 Nm при 62–68 A) → [phase-0-feasibility.md](docs/physics/phase-0-feasibility.md)
- **поправка K_t:** прошивка moteus считает K_t = (3/2)(1/√3)(60/2π)/Kv ≈ 8.27/Kv, а не 60/(2π·Kv). Для mj5208 (Kv 330) K_t = 0.0251 Nm/A (было 0.029, −15 %); измеренный Kv devkit-мотора 304 → 0.0272. Peak c1 = 0.50 Nm (было 0.58). Измеренные R_ph = 0.047 Ω, L = 28.6 µH, 14 полюсов (mjbots blog 2025-04-24)
- **поправка скорости:** moteus ограничивает фазное напряжение до ≈0.4·V_bus (voltage circle с margin 0.15), холостая скорость при 12 V — 2740 rpm, при 14.8 V — 3380 rpm, а не 4900 rpm по правилу Kv·V. Колено 1.7 Nm у r4.11 при 12 V — уже на 830 rpm
- **swing-up (`poetry run phase0-swingup --sweep`):** требуемый момент импульса H = I_w·ω_max не зависит от I_w: 0.19–0.28 Nms при раскачке с ограничением ≤0.5 Nm (1–2 качания, 1.1–1.3 s), 0.44 Nms при прямом подъёме на 1.7 Nm (0.3–0.4 s). Окно: I_w ≥ 0.0014 (раскачка) / 0.0022 kg·m² (прямой подъём) при 12 V; рекомендация I_w ≈ 0.003 kg·m² (колесо 2025 г. с 0.0008 не проходит). RMS ток при раскачке 5–11 A ~1 s — термически несущественно
- **батарея на оси вращения:** на верхнем конце (0.25 m) пакет 120 g даёт +30 % к G, моменту и энергии swing-up при неизменной постоянной времени; вариант — чуть ниже оси как противовес
- **тепловая модель мотора (не измерено):** P = 1.5·I²·R, R_th 3–6 K/W, ΔT 60 K → 12–17 A → 0.30–0.42 Nm continuous; совпадает с 12 A bare-рейтингом r4.11. Проверка на стенде — Phase 1
- ROADMAP Phase 0: torque budget посчитан (пункт 2 закрыт); gate в целом NOT READY — нет CAD-модели масс, теплового теста, cogging, выбора сенсора
- новое в `software/sim`: `app/phase0_swingup.py` (energy pumping + LQR catch с реальной огибающей момент/скорость), `phase0.toml` с provenance по блокам, 15 тестов

**04.09.2026**
- добавлен воспроизводимый Phase 0 pre-check (`software/sim/phase0.toml`, `poetry run phase0`) и документ с формулами/критериями (`docs/physics/phase-0-feasibility.md`); все неподтверждённые значения явно оставлены planning ranges или `UNKNOWN`
- предварительный результат на pessimistic corner (0.65 kg, CoM 0.21 m, $\theta=20°$): mj5208+c1 даёт только 1.26× peak margin → FAIL относительно порога 1.5×; mj5208+r4.11 даёт 3.71× → PASS по peak torque, но это не финальный выбор
- Phase 0 пока `NOT READY`: нужны CAD/BOM mass model, continuous thermal torque и cogging mj5208, $H_{swingup}$ из constrained simulation, validation выбранного sensor/estimator
- добавлен provisional sampled-LQR sensor sweep с saturation, torque-speed envelope и command delay; на pessimistic planning corner для r4.11: 75 Hz PASS / 50 Hz FAIL, 10 ms PASS / 15 ms FAIL, noise 1°+10°/s PASS / 2°+20°/s FAIL (5/5 trials, initial angle 10°); повторить после выбора реального sensor/estimator

**11.08.2026**
- ресёрч mjbots/moteus: компания из США (Cambridge, MA, Josh Pieper, 2019), всё open-source (Apache 2.0). Интерфейс CAN-FD 5 Mbps, библиотеки Python/C++/Rust, GUI tview. Рекомендуемый стек: mj5208 + moteus-c1 + Raspberry Pi + pi3hat (CAN-FD + IMU на борту) → [hardware.md → Driver: moteus](docs/hardware/hardware.md)
- ⚠️ mjbots: shipping holiday, новые заказы отправляются с 17.08.2026

**10.08.2026 (4)**
- **решение пересмотрено: мотор = mjbots mj5208 ($74) + драйвер moteus** ([mj5208](https://mjbots.com/products/mj5208), [moteus-c1 $69](https://mjbots.com/products/moteus-c1) / [r4.11 $94](https://mjbots.com/products/moteus-r4-11)). Причина: отказ от SimpleFOC снял лимит 5 A — mj5208 (Kv 330, K_t≈0.029) с c1 даёт 0.58 Nm peak, с r4.11 до 1.7 Nm при 193 g (8.8 Nm/kg — лучший specific torque из всех), ω_nl@4S ≈ 4900 rpm — momentum перестаёт быть проблемой. Motor+driver+encoder ≈ $143 — та же цена, что GL40+c1. Devkit-пара: плата ставится на задний магнит ротора, энкодер на борту
- открытые вопросы перед заказом: cogging mj5208 (не gimbal-обмотка; у moteus есть anti-cogging — проверить на форуме/discord mjbots); доставка из США (+~25–30% VAT/пошлина, сроки); continuous torque на c1 без обдува всего 0.14 Nm — вероятно хватает для удержания, иначе r4.11
- GL40 KV70 остаётся запасным вариантом (EU-склад, быстрая доставка)

**10.08.2026 (3)**
- **решение: мотор = CubeMars GL40 KV70** (вариант с энкодером, [OpenELAB €110](https://openelab.io/products/cubemars-gl40-kv70-bldc-gimbal)). Обоснование: лучший specific torque (4.6 Nm/kg), 107 g, 940 rpm @ 4S. Коммиты решения: 4S обязателен (на 3S лишь 0.37 Nm); потолок 0.49 Nm — запас k≈1.5–1.9 при θ_max=20° с батареей на оси, Phase 0 подтверждает реальными массами; перед заказом уточнить тип/интерфейс энкодера у OpenELAB (не раскрыт) или взять base + AS5048A; болтовое поле ротора — из STEP-чертежа CubeMars
- покупка НЕ оформлена — ждёт Phase 0 gate

**10.08.2026 (2)**
- решение: батарея на оси вращения → почти не добавляет m·l; порог момента снижен до ~0.45 Nm @ 4S — у GL40 KV70 появился реальный запас
- swing-up: разгон-реверс колеса = стандартный energy pumping; сила «кика» ограничена K_t·I_max независимо от RPM — метрика — momentum capacity I_w·ω, добирать инерцией колеса и многотактовой раскачкой, не высоким Kv
- второй ресёрч: +8 новых кандидатов (SteadyWin, MyActuator/LK-TECH) → top-7 buy list с URL в [motor-candidates.md](docs/hardware/motor-candidates.md); новый класс: сервоприводы со встроенным FOC-драйвером и энкодером (CAN) — RMD-L-5015 (0.82 Nm, 174 g, ~€72)

**10.08.2026**
- сформулированы критерии выбора BLDC-мотора ([hardware.md](docs/hardware/hardware.md#motor-selection-criteria)): parametric torque budget, desktop DIY-kit, батарея на борту (3S–4S), мотор ≤ €120
- ресёрч кандидатов завершён: 15 моторов оценено → [motor-candidates.md](docs/hardware/motor-candidates.md). Shortlist: CubeMars GL40 KV70 (€85–110, 0.49 Nm@4S — ровно на пороге), iPower GM5208-24 (€52, риск по swing-up), CubeMars G60 KV55 (€132, 1.0 Nm — stretch). Выводы: 4S обязателен; в бюджете рынок упирается в ~0.5 Nm; драйвер нужен ≥5 A FOC

**09.08.2026**
Проект воскрешён: перенесён из `archive/projects/` обратно в `projects/`. Состояние на момент заморозки: в симуляции всё работает (SB3/PPO, swing-up, ONNX + браузерная визуализация), железо упёрлось в узкий диапазон рабочих параметров (момент двигателя, точность измерений). LQR посчитан, но колесо не останавливалось.

**01.11.2025**
Сегодня я решил похоронить обратный маятник. Все очень здорово выглядит в симуляторе, пока не нужно проектировать реальное устройство. Легко стабилизировать, когда у тебя измерения произвольной точности и бесконечный момент двигателя. В реальности, есть очень узкий набор параметров, при котором баланс достижим. Этот проект уже занял у меня кучу времени, и я не хочу тратить на него свою жизнь. Он, как настоящий маятник из трансерфинга реальности, просто оттягивает мою жизненную энергию на себя, больше я не буду его кормить. Это был проект, над которым у меня было 100% контроля и 0% пользы для меня или для мира.

**05.10.2025**
- estimated maximal angular velocity, it corresponds to the reality
- fixed jerky angle at the top, now it is smooth
- calculated LQR stabilization (but the wheel does not stop), needs more tuning, or since it does not have a concept of time (no integral part) there is no sufficient information for control
- → next: stabilize in the upright position using LQR

**03.10.2025**
- implemented active oscillation dumping, [simulation](https://colab.research.google.com/drive/1u6tl5SG2cvKg8DLndMQ9u2ieP07KyDuc#scrollTo=PbFrm5GsAxk4)
- dumping force is just $-\dot{\theta}$

**07.09.2025**
- switched back to MPU6050, since I need only roll
- [x] redesign MPU position to rotate around X-axis (ordered a new board)
- used https://github.com/TKJElectronics/KalmanFilter/tree/master library to get roll without a drift
- [x] refactor code, incapsulate MPU-related code for improved readability

**20.05.2025**
- used `kwokkayan/SparkFun MPU-9250 Digital Motion Processing (DMP) Arduino Library (For ESP32)@^1.0.1` library for IMU, it worked, didn't trigger a reset cycle
- only `roll` is a reliable reading now
- → 🔥 find a reliable value for an angle in the vertical plane (use 6DOF and implement sensor fusion)
- → try a lighter motor, see if it has enough torque to rotate the wheel
- → 🔥 redesign a rod, add mounting wholes for the PCB
- → stabilize the pendulum in the bottom position (with PID, then NN)
- => feels like I want to abandon using Gyro... and get back to the design with an angular encoder
	- try 6DOF algorithms so far

**17.05.2025**
- → select a bearing with axial load tolerance
- → fix IMU init issue, previous (balancing robot) firmware also turns into reboot (try with Arduino, then with a SparkFun WROOM board)
- → compare different IMU modules `ICM-20948`, `BMI270`, `BNO055`, `BMI088`, `BMI323`
- ~~→ забрать тиски у Димана~~
- → забрать дрель у Алины
- → уменьшить толщину стенки, где крепляется двигатель (<7mm) или найти более длинный болт M3 (>8mm)
- → review TriNamic stepper motor drivers, e.g. TMC2209
- [ch34xser_macos driver should be installed](https://github.com/WCHSoftGroup/ch34xser_macos?tab=readme-ov-file)
- stepper enabled
- issues with MPU, goes into a reboot cycle, check if the board is functional
```
clk_drv:0x00,q_drv:0x00,d_drv:0x00,cs0_drv:0x00,hd_drv:0x00,wp_drv:0x00
mode:DIO, clock div:2
load:0x3fff0030,len:1184
load:0x40078000,len:13232
load:0x40080400,len:3028
entry 0x400805e4
before MPU begin
[   647][E][Wire.cpp:499] requestFrom(): i2cWriteReadNonStop returned Error 263
[   655][E][Wire.cpp:499] requestFrom(): i2cWriteReadNonStop returned Error -1
[   662][E][Wire.cpp:499] requestFrom(): i2cWriteReadNonStop returned Error -1
[   669][E][Wire.cpp:499] requestFrom(): i2cWriteReadNonStop returned Error -1
Guru Meditation Error: Core  1 panic'ed (LoadProhibited). Exception was unhandled.
```

**29.03.2025**
- сделал визуализацию в браузере, TypeScript, стабилизировал с помощью экспортированной ONNX-модели
- → до обучить модель, чтобы она стремилась остановить маятник в верхнем положении (2х фазное обучение, разная функция вознаграждения на каждом этапе)
- ✅ сделать задачи из TODO-листа по вебу - задеплоить
- → опубликовать статью по экспорту модели в ONNX
- → опубликовать статью по проекту на данной фазе
- → dedicated landing page
- → publish articles on LinkedIn

**18.03.2025**
- `action_net` использует нормализацию с `tahn`-функцией, потом масштабирование
```python
mean_actions = self.policy.action_net(latent_pi)  
normalized_actions = torch.tanh(mean_actions)  
scaled_actions = self.action_low + (0.5 * (normalized_actions + 1.0) * (self.action_high - self.action_low))
```
- удалось успешно экспортировать модель в ONNX в один прогон, визуализировать с ней стабилизацию в исходном окружении
- ✅ визуализировать все красиво в браузере, позволить пользователю "пинать" маятник мышкой с разных сторон

**15.03.2025**
- использовал [claude.ai](https://claude.ai), он отлично и глубоко анализирует проблемы
- убедился, что архитектуры PyTorch и ONNX-моделей должны совпадать
- собрал ONNX-модель вручную, наполнил ее параметрами из PyTorch-модели, результат получился почти идентичным, если сравнивать послойно
- Но! результат прогона полной PPO-модели сильно отличается, PPO (-4, 4), тогда, как послойный запуск дает -53..53, там есть еще какая-то пост-обработка
- ✅ выяснить, что за пост-обработка в PPO-модели присутствует
- ✅ добавить ее в ONNX-модель
- ✅ сделать базовую визуализацию с ONNX-моделью

**13.03.2025**
- вчера экспортировал модель из PyTorch в ONNX, возникли такие проблемы:
	- экспортированная модель не повторяет архитектуру исходной сети, получается какой-то сложный граф
	- на выходе 3 значения (action, value, log_prob)
	- результат разный на одних и тех же данных, возможно, там появился слой drop-out
	- выходное значение на несколько порядков отличается от выходного значения исходной нейронной сети (но можно подобрать коэффициент сжатия)
- **идеи**
	- экспортировать только `actor` network
	- ✅ try to code a simple PyTorch model and export it, the architecture should be the same, it should give the same values
	- загрузить параметры PyTorch модели вручную и самому реализовать сеть
	- ✅ собрать ONNX модель самому, просто скопировав параметры из словаря PyTorch модели
	- Реализовать nn.Model архитектуру `actor` network, загрузить в нее параметры из исходной ActorCritic, экспортировать в ONNX, убедиться, что архитектура осталась прежней и значения выдаются такие же.
**23.02.2025**
- exported model to ONNX format, can be executed separately from PyTorch environment
- → render using ONNX model
- → implement forward pass in C++ (or TinyTorch)

**01.02.2025**
 - tried a new reward function: 
   $r = -(\theta^2 + 0.1\cdot\dot\theta^2 + 0.001\cdot\dot\phi^2) -  termination\_penalty$
   - it can learn how to balance from a narrow set of angle upwards
   - it can learn how to swing-up
   - but how to combine those skills?
   - → try to train one set of skills, then pre-load the model and train another set of skills, then mix conditions

**27.01.2025**
- все зависит от функции вознаграждения, в нижнем положении, он отлично научился раскачиваться
- но с умением раскачиваться, ему выгодней просто какое-то время находиться в верхней половине, над горизонтом
- → поискать функции вознаграждения у тех, кто уже делал раскачивание
- → раскачать классическую задачу с маятником на тележке
- → [try this reward function](https://github.com/openai/gym/blob/master/gym/envs/classic_control/pendulum.py)

**26.01.2025**
Run in Kaggle notebook on GPU: seems no benefit:
- CPU: 50,000 steps Elapsed time: **114.079** seconds
- GPU: Elapsed time: **149.339** seconds
- → consider this [repo](https://github.com/0xangelo/gym-cartpole-swingup) for Swing-Up and inheritance pattern
- → render model usage phase with Manim

**23.01.2025**
- decided not to vectorize the environment for now, too long to study this topic and change the env to support it.
- run CartPole on Kaggle, checked GPU availability.
- → train to swing-up on Kaggle, reuse trained model locally for visualization
- → show training graph in Kaggle (reward change)

**21.01.2025**
- stabilized FIP with SB3, reward function was crucial, it sets accents on which aspects of the reality the model should focus, eventually it became more aggressive, with higher exploration coefficient.
- → visualize mean reward and other params during training
- → visualize NN internals, how it operates from the inside
- → next: vectorize to speedup training → CANCELLED: too long to study
- → next: swing-up, even more aggressive control

**19.01.2025**
- stabilized CartPole-v1 with SB3, the original Env had a discrete action space, I made it continuous, it made the system more robust to disturbances
- an external disturbance was added during the testing phase
- pole angle threshold was increased during the testing phase to allow bigger movements before the episode ends
- → ✅ stabilize FIP with SB3
- → train a cart-pole to swing-up, allow to apply a bigger force
- → vectorized environments with GPU @Kaggle → publish an article

**18.01.2025**
- restored stabilization with LQR
- rendered env parameters
- → ✅ stabilize cart-pole with stable baselines3
- → ✅ FIP with baselines3 (find right initial conditions)

**14.01.2025**
- `FlywheelInvertedPendulumEnv`, internal variables are not accessible due to wrapper classes, it worked before, have no idea why it stopped working
- go for FIP directly, forget about ball catcher, rather remove it
- → ✅ finish HF
- → try Cart Pole and Moon Lander locally with SB3
- → learn fast-ai course

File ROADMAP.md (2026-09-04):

# Roadmap — resurrection 2026

Принцип: **hardware feasibility first**. Проект умер в 2025 из-за разрыва симуляция↔железо. В этот раз ни одной строчки кода обучения, пока честная симуляция с реальными параметрами железа не покажет, что хотя бы LQR стабилизирует систему.

## Phase 0 — Feasibility math (go/no-go)

- [ ] Собрать реальные параметры: масса и длина маятника, положение центра масс, момент инерции колеса, кривая момент/скорость мотора-кандидата
- [x] Посчитать максимальный восстанавливаемый угол (torque budget): при каком отклонении момента мотора ещё хватает → [phase-0-feasibility.md](docs/physics/phase-0-feasibility.md) (2026-09-04): mj5208 + r4.11 держит 20° с запасом 3.7× на пессимистичном углу; swing-up требует H ≈ 0.2–0.45 Nms → I_w ≥ 0.0015–0.0022 kg·m², рекомендация 0.003
- [ ] Посчитать бюджет по сенсорам: допустимые шум угла и задержка контура при требуемой полосе управления
- [ ] Итог: границы окна параметров (масса колеса / длина стержня / момент мотора), внутри которого баланс достижим

## Phase 1 — Component selection

- [ ] Подобрать BLDC-мотор: вес, момент (включая момент на скорости, не только stall), KV, наличие места под энкодер — критерии: [hardware.md → Motor selection criteria](docs/hardware/hardware.md#motor-selection-criteria); кандидаты: [motor-candidates.md](docs/hardware/motor-candidates.md) → **выбран mjbots mj5208 + moteus (c1/r4.11)** (2026-08-10, заказ после Phase 0 gate; GL40 KV70 — запасной)
- [ ] Драйвер / control PCB: FOC-драйвер (SimpleFOC / ODrive-класс), MCU (ESP32?), энкодер на моторе, IMU или угловой энкодер на оси маятника → **драйвер выбран: moteus r4.11** (2026-09-04, c1 не проходит continuous и 20°); хост и сенсор угла — открыты
- [ ] Питание: батарея vs провод, вес батареи входит в модель → **4S LiPo на оси вращения маятника** (2026-09-04: на верхнем конце +30 % к моменту и энергии swing-up)
- [ ] Механика: длина стержня, масса/радиус колеса — оптимизировать по результатам Phase 0, а не наоборот → CAD в OpenSCAD: [cad-spec.md](docs/hardware/cad-spec.md), `hardware/cad/` (2026-09-04); печать после проверки паттерна статора

## Phase 2 — Honest simulation (gate)

Симуляция обязана включать: реальную кривую момент/скорость мотора, ограничение по току, шум и частоту IMU/энкодера, задержку контура, дискретизацию по времени, трение.

- [ ] Обновить модель в симуляторе под выбранные компоненты
- [ ] LQR стабилизирует верхнее положение и останавливает колесо (вес на скорость колеса в функции стоимости)
- [ ] Swing-up + catch с реальными ограничениями момента
- [ ] **Gate:** если LQR не держит систему в честной симуляции — назад в Phase 1, железо не покупаем/не печатаем

## Phase 3 — Build & classical control

- [ ] Спроектировать и изготовить механику (по параметрам из Phase 1/2)
- [ ] Собрать электронику, прошивка: чтение угла, FOC-контур момента
- [ ] Стабилизация LQR на реальном железе
- [ ] Swing-up на реальном железе

## Phase 4 — NN / DRL + content

- [ ] Перенести обученную в симуляции политику на устройство (sim-to-real)
- [ ] Статьи: экспорт в ONNX, кейс проекта (Хабр + англоязычный портал)
- [ ] Промо-видео / выставки — см. [цели в README](README.md)

## Log

- **2026-08-09** — roadmap создан, проект воскрешён из архива
- **2026-08-10** — критерии выбора мотора сформулированы ([hardware.md](docs/hardware/hardware.md#motor-selection-criteria))
- **2026-09-04** — torque budget посчитан, драйвер moteus r4.11 выбран, батарея на оси ([phase-0-feasibility.md](docs/physics/phase-0-feasibility.md))

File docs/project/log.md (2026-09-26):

# Project log

**25.09.2026 (20) — T-005 разделена по bench setup и измерительным gates**
- единая T-005 разложена на T-005.A–F: desk-stand timing, guarded rotating
  losses, static torque calibration, loaded torque-speed/voltage, thermal limit
  и публикация measured inputs; порядок и dependencies теперь заданы в
  [tasks.md](tasks.md)
- physical inspection, bidirectional position-step и centered friction/cogging
  before/after anticogging остаются завершёнными результатами из записей
  20.09.2026; открытая T-005.A требует отдельно ограничить command-to-motion
  delay, tail latency и tracking по существующим данным или повторному run
- static ±8 A fixture уже спроектирован, поэтому его calibration идёт рядом с
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

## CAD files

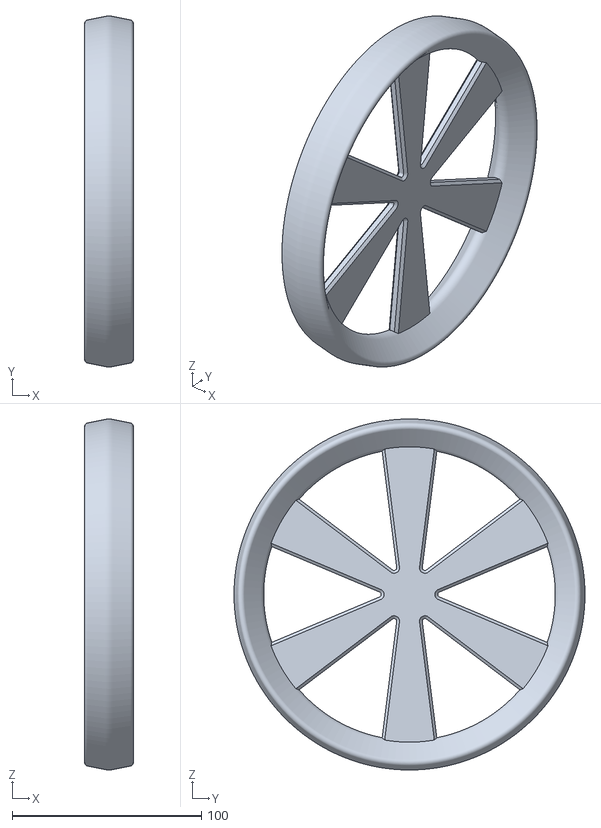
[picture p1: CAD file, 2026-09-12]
software/sim/learning/mujoco/assets/wheel.stl
25.9 x 185.6 x 185.6

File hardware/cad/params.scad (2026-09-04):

// All dimensions in mm, densities in g/mm^3. Source of truth: docs/hardware/cad-spec.md.
// Frame: origin at the axle centre on the rod mid-plane; Z up the upright rod;
// Y along the axle away from the table edge; X along the table edge.

bed = 220;
rho_pla = 1.25e-3;
rho_steel = 7.85e-3;

rod_len = 250;                 // axle axis to motor axis

// ---- wheel (native axis Z) ----
wheel_d = 280;
rim_radial = 8;
rim_axial = 8;
spokes = 8;                    // two per quadrant
spoke_w = 4;
spoke_t = 8;
hub_d = 60;
hub_t = 5;
hub_bc_d = 45;                 // quadrant flange screws
hub_bore_d = 10;
flange_ri = 13;                // quadrant flange sector inner radius (clears rotor screw heads)
pocket_n = 16;                 // tuning holes every 22.5 deg, first at 11.25 deg
bolt_fit = 8;                  // standard number of M6 tuning bolts
lap_len = 8;                   // rim half-lap length along the rim

// ---- motor mj5208 ----
motor_d = 63;
motor_len = 25;
rotor_bc_d = 17;
rotor_n = 3;
stator_pitch = 25;             // TO VERIFY against the mjbots 2D drawing (square assumed)
stator_n = 4;
flange_d = 70;
flange_plate_t = 6;

// ---- pivot ----
axle_d = 8;
axle_len = 120;
bearing_od = 22;
bearing_w = 7;
bearing_spacing = 40;
axle_overhang = 60;            // table edge to rod mid-plane
axle_height = 30;              // table top to axle centre
table_min = 18;
table_max = 40;

// ---- rod ----
beam_w = 20;                   // X
beam_h = 20;                   // Y
flange_t = 3;
web_t = 3;
tongue_len = 40;
beam_end = rod_len - 60;       // tongue ends here so the beam fits the bed diagonally
clamp_size = [30, 20, 30];     // X, Y, Z around the axle
battery = [35, 25, 75];        // X, Y, Z as mounted on the -Y face
hat = [49, 58];                // RPi/pi3hat hole pattern: X, Z
hat_hole = 2.8;

// ---- stand ----
jaw_w = 40;
clamp_wall = 8;
throat = 60;
arm_w = 40;

// ---- fits and hardware ----
clearance = 0.3;
M3 = 3.4;
M6 = 6.4;
M8 = 8.4;
nut_m3_af = 5.5;
nut_m3_h = 2.4;
nut_m8_af = 13;
nut_m8_h = 6.5;
$fn = 72;

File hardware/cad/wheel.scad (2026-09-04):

// Reaction wheel: four identical quadrants + hub plate, Ø280, printed rim and
// M6 tuning bolts provide the inertia. Native frame: wheel axis = Z, parts from z = 0.
include <lib.scad>

part = "quadrant";   // quadrant | hub | bolts | wheel

wr = wheel_d / 2;                 // rim outer radius
ri = wr - rim_radial;             // rim inner radius
rm = wr - rim_radial / 2;         // rim mid radius (holes, bolts)
la = lap_len / rm * 180 / PI;     // lap angle, deg
half = rim_axial / 2 - clearance / 2;

module quadrant() {
    difference() {
        union() {
            // full-height rim between the laps
            arc(la / 2, 90 - la / 2, wr, ri, rim_axial);
            // lower tongue at the 0 deg seam, upper tongue at the 90 deg seam
            arc(-la / 2, la / 2 + 0.01, wr, ri, half);
            translate([0, 0, rim_axial / 2 + clearance / 2]) arc(90 - la / 2 - 0.01, 90 + la / 2, wr, ri, half);
            // two spokes
            for (a = [22.5, 67.5]) rotate([0, 0, a]) translate([flange_ri + 2, -spoke_w / 2, 0]) cube([ri + 1 - (flange_ri + 2), spoke_w, spoke_t]);
            // hub flange sector (0.5 deg gap to the neighbours)
            arc(0.5, 89.5, hub_d / 2, flange_ri, hub_t);
        }
        // lap screw at the 0 deg seam
        translate([rm, 0, 0]) hole(M3, rim_axial);
        // flange screws
        for (a = [22.5, 67.5]) rotate([0, 0, a]) translate([hub_bc_d / 2, 0, 0]) hole(M3, hub_t);
        // tuning holes: pocket_n / 4 per quadrant
        for (i = [0 : pocket_n / 4 - 1]) rotate([0, 0, 180 / pocket_n + i * 360 / pocket_n]) translate([rm, 0, 0]) hole(M6, rim_axial);
    }
}

module hub() {
    difference() {
        cylinder(d = hub_d, h = hub_t);
        hole(hub_bore_d, hub_t);
        at_circle(rotor_bc_d, rotor_n) hole(M3, hub_t);
        // quadrant screws with trapped nuts on the motor side (z = 0)
        at_circle(hub_bc_d, 8, 22.5) {
            hole(M3, hub_t);
            translate([0, 0, -0.01]) hex_pocket(nut_m3_af, nut_m3_h);
        }
    }
}

// Steel hardware for the mass model: bolt_fit x (M6x20 bolt, head, nut) at the rim.
module bolts() {
    at_circle(2 * rm, bolt_fit, 180 / pocket_n) {
        translate([0, 0, -4]) cylinder(d = 10, h = 4);                  // head
        translate([0, 0, -4]) cylinder(d = 6, h = 24);                  // shank
        translate([0, 0, rim_axial]) cylinder(d = 10, h = 5, $fn = 6);  // nut
    }
}

// Assembled wheel for inertia and for the assembly file.
module wheel() {
    hub();
    translate([0, 0, hub_t]) for (a = [0 : 90 : 270]) rotate([0, 0, a]) quadrant();
}

if (part == "quadrant") quadrant();
else if (part == "hub") hub();
else if (part == "bolts") translate([0, 0, hub_t]) bolts();
else if (part == "wheel") wheel();
else assert(false, str("unknown part: ", part));

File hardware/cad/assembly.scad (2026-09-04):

// Full pendulum on its stand. angle = pendulum angle from upright about Y (deg).
include <lib.scad>
use <wheel.scad>
use <rod.scad>
use <stand.scad>

angle = 0;
show_table = true;

module motor() translate([0, 0, rod_len]) ycyl(motor_d, motor_len, flange_plate_t / 2);

// wheel native Z -> pendulum +Y, hub plate against the rotor face
module wheel_asm() translate([0, flange_plate_t / 2 + motor_len, rod_len]) rotate([-90, 0, 0]) {
    wheel();
    translate([0, 0, hub_t]) bolts();
}

module pendulum(a = angle) rotate([0, a, 0]) {
    beam();
    motor_flange();
    motor();
    wheel_asm();
}

module axle() ycyl(axle_d, axle_len, -105);

module table_top() translate([-200, -axle_overhang - 400, -axle_height - 25]) cube([400, 400, 25]);

stand();
axle();
pendulum();
if (show_table) %table_top();

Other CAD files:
hardware/cad/check.scad
hardware/cad/lib.scad
hardware/cad/rod.scad
hardware/cad/stand.scad

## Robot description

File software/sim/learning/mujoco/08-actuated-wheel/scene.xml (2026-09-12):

<mujoco model="actuated flywheel pendulum">
  <compiler angle="degree" meshdir="../assets" inertiafromgeom="true"/>
  <option timestep="0.002" gravity="0 0 -9.81"/>
  <statistic center="0 0 0.4" extent="0.8"/>

  <visual>
    <headlight ambient="0.35 0.35 0.35" diffuse="0.8 0.8 0.8"/>
  </visual>

  <asset>
    <texture name="checker" type="2d" builtin="checker" rgb1="0.15 0.15 0.15" rgb2="0.85 0.85 0.85" width="256" height="256"/>
    <material name="checker-floor" texture="checker" texrepeat="2 2" texuniform="true" reflectance="0.1"/>
    <material name="stand-metal" rgba="0.38 0.42 0.48 1" specular="0.50" shininess="0.40"/>
    <material name="beam-material" rgba="0.85 0.35 0.15 1"/>
    <material name="motor-metal" rgba="0.28 0.30 0.34 1" specular="0.75" shininess="0.65"/>
    <material name="wheel-metal" rgba="0.62 0.66 0.72 1" specular="0.95" shininess="0.85"/>
    <mesh name="wheel-mesh" file="wheel.stl" scale="0.001 0.001 0.001" inertia="exact"/>
  </asset>

  <worldbody>
    <light name="key-light" pos="-0.4 -0.5 1.2" directional="true" dir="0.3 0.4 -1" diffuse="0.75 0.75 0.75"/>
    <geom name="floor" type="plane" size="1 1 0.1" material="checker-floor"/>

    <geom name="support-post" type="box" pos="0 0.18 0.24" size="0.04 0.04 0.24" material="stand-metal"/>
    <geom name="support-axle" type="cylinder" fromto="0 0 0.45 0 0.14 0.45" size="0.01" material="stand-metal"/>
    <geom name="pivot-cap" type="cylinder" fromto="0 -0.012 0.45 0 0.012 0.45" size="0.018" contype="0" conaffinity="0" material="stand-metal"/>

    <body name="pendulum" pos="0 0 0.45">
      <joint name="pivot" type="hinge" axis="0 1 0" damping="0.0002"/>
      <geom name="beam" type="capsule" fromto="0 0 0 0 0 0.25" size="0.012" mass="0.064" contype="0" conaffinity="0" material="beam-material"/>
      <geom name="motor-housing" type="cylinder" pos="0 0 0.25" euler="90 0 0" size="0.0315 0.0125" mass="0.193" contype="0" conaffinity="0" material="motor-metal"/>

      <body name="wheel" pos="0 0 0.25">
        <joint name="wheel-hinge" type="hinge" axis="0 1 0" damping="0.005"/>
        <geom name="wheel-visual" type="mesh" mesh="wheel-mesh" pos="0 -0.027 0" euler="0 0 90" density="1250" contype="0" conaffinity="0" material="wheel-metal"/>
      </body>
    </body>
  </worldbody>

  <actuator>
    <motor name="wheel-torque" joint="wheel-hinge" gear="1" ctrllimited="true" ctrlrange="-1.7 1.7"/>
  </actuator>
</mujoco>

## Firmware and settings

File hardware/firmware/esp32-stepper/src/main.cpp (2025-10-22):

/**
 * AI-controlled flywheel inverted pendulum firmware.
 * 
 * Parts:
 *  - ESP32 DevKit-C
 *  - Nema17 stepper motor
 *  - A4988 stepper driver
 *  - MPU6050
 * 
 * @author Sergey Royz (zjor.se@gmail.com) 
 * @version 0.1
 * @date 2025-05-17 - ...
 */
#include <Arduino.h>
#include <Wire.h>
#include <Adafruit_MPU6050.h>
#include <Adafruit_Sensor.h>
#include <Kalman.h>

#include <math.h>

#include "pinout.h"
#include "stepper/stepper.h"
#include "FixedRateExecutor.h"
#include "MPU.h"
#include "MathUtils.h"

// pulses per revolution
#define PPR               1600

#define CPU_FREQ_MHZ      240
#define CPU_FREQ_DIVIDER  120
#define TICKS_PER_SECOND  (200000 * (CPU_FREQ_MHZ / CPU_FREQ_DIVIDER))
#define PULSE_WIDTH       1

/**
 * How to calibrate:
 * - set to zero
 * - get a settled value
 */
#define THETA_BIAS_DEG  -2.00f

// LQR params
#define K_THETA         40000.0
#define K_THETA_DOT     250.0
#define K_PHI           0.0
#define K_PHI_DOT       -110.0

void initMPU();
void initTimerInterrupt();
void updateStepperVelocity(unsigned long);
void updateControl(unsigned long);
void log();

FixedRateExecutor logger(25000, log);

static inline float accelRollDegFrom(const sensors_event_t&);
static inline float gyroRollRadFrom(const sensors_event_t&);

hw_timer_t * timer = NULL;

Stepper stepper(PIN_STEPPER_EN, PIN_STEPPER_DIR, PIN_STEPPER_STEP, TICKS_PER_SECOND, PPR, PULSE_WIDTH);

MPU mpu(THETA_BIAS_DEG);
float last_ms = 0;

// stepper params
float velocity = 0.0;
float accel = 0.0;

void setup() {
  setCpuFrequencyMhz(CPU_FREQ_MHZ);

  Serial.begin(115200);
  Wire.begin();
  Wire.setClock(1000000UL);

  initTimerInterrupt();
  delay(250);
  mpu.init();

  stepper.init();
  stepper.setEnabled(true);
  last_ms = millis();
}

void loop() {
  unsigned long nowMicros = micros();
  updateStepperVelocity(nowMicros);
  updateControl(nowMicros);

  unsigned long now = millis();
  float dt = (now - last_ms) / 1000.0f;
  mpu.updateAngles(dt);
  last_ms = now;

  logger.tick(nowMicros);
}

void updateStepperVelocity(unsigned long nowMicros) {
  static unsigned long timestamp = micros();
  if (nowMicros - timestamp < 50 /* 20 kHz */) {
    return;
  }
  
  float dt = ((float) (nowMicros - timestamp)) * 1e-6;
  velocity += accel * dt;
  stepper.setVelocity(velocity);
  timestamp = nowMicros;
}

void updateControl(unsigned long nowMicros) {
  static unsigned long timestamp = micros();
  if (nowMicros - timestamp < 1000 /* 1kHz*/) {
    return;
  }

  float theta = mpu.getAngleRad();
  theta = (theta > 0) ? theta - M_PI : theta + M_PI;
  if (abs(theta) < M_PI / 16) {
    float theta_dot = mpu.getAngularVelocityRad();
    float phi = 0; //stepper position
    float phi_dot = velocity; //TODO: convert to radians/sec

    accel = K_THETA * theta + 
            K_THETA_DOT * theta_dot + 
            K_PHI * phi + 
            K_PHI_DOT * phi_dot;

    accel = clamp(accel, 150);
  } else {
    accel = 0;
    velocity = 0;
  }
  timestamp = nowMicros;
}

void IRAM_ATTR onTimer() {
  stepper.tick();
}

void initTimerInterrupt() {
  // 80MHz / 80 / 5 = 200kHz  
  timer = timerBegin(0 /* timer ID */, CPU_FREQ_DIVIDER /* CPU frequency divider */, true /* count up */);
  timerAttachInterrupt(timer, &onTimer, true /* edge */);
  timerAlarmWrite(timer, 5 /* int at counter value */, true /* reload counter */);
  timerAlarmEnable(timer);
}

void log() {
  Serial.printf("%.2f\t%.2f\n", mpu.getAngleDeg(), accel);
}

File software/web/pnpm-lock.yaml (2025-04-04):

lockfileVersion: '9.0'

settings:
  autoInstallPeers: true
  excludeLinksFromLockfile: false

importers:

  .:
    dependencies:
      '@types/jest':
        specifier: ^29.5.14
        version: 29.5.14
      '@types/node':
        specifier: ^22.13.14
        version: 22.13.14
      chart.js:
        specifier: ^4.4.8
        version: 4.4.8
      copy-webpack-plugin:
        specifier: ^13.0.0
        version: 13.0.0(webpack@5.98.0)
      html-webpack-plugin:
        specifier: ^5.6.3
        version: 5.6.3(webpack@5.98.0)
      onnxruntime-web:
        specifier: ^1.21.0
        version: 1.21.0
      ts-loader:
        specifier: ^9.5.2
        version: 9.5.2(typescript@5.8.2)(webpack@5.98.0)
      ts-node:
        specifier: ^10.9.2
        version: 10.9.2(@types/node@22.13.14)(typescript@5.8.2)
      typescript:
        specifier: ^5.8.2
        version: 5.8.2
      webpack:
        specifier: ^5.98.0
        version: 5.98.0(webpack-cli@6.0.1)
      webpack-cli:
        specifier: ^6.0.1
        version: 6.0.1(webpack-dev-server@5.2.1)(webpack@5.98.0)
      webpack-dev-server:
        specifier: ^5.2.1
        version: 5.2.1(webpack-cli@6.0.1)(webpack@5.98.0)

packages:

  '@babel/code-frame@7.26.2':
    resolution: {integrity: sha512-RJlIHRueQgwWitWgF8OdFYGZX328Ax5BCemNGlqHfplnRT9ESi8JkFlvaVYbS+UubVY6dpv87Fs2u5M29iNFVQ==}
    engines: {node: '>=6.9.0'}

  '@babel/helper-validator-identifier@7.25.9':
    resolution: {integrity: sha512-Ed61U6XJc3CVRfkERJWDz4dJwKe7iLmmJsbOGu9wSloNSFttHV0I8g6UAgb7qnK5ly5bGLPd4oXZlxCdANBOWQ==}
    engines: {node: '>=6.9.0'}

  '@cspotcode/source-map-support@0.8.1':
    resolution: {integrity: sha512-IchNf6dN4tHoMFIn/7OE8LWZ19Y6q/67Bmf6vnGREv8RSbBVb9LPJxEcnwrcwX6ixSvaiGoomAUvu4YSxXrVgw==}
    engines: {node: '>=12'}

  '@discoveryjs/json-ext@0.6.3':
    resolution: {integrity: sha512-4B4OijXeVNOPZlYA2oEwWOTkzyltLao+xbotHQeqN++Rv27Y6s818+n2Qkp8q+Fxhn0t/5lA5X1Mxktud8eayQ==}
    engines: {node: '>=14.17.0'}

  '@jest/expect-utils@29.7.0':
    resolution: {integrity: sha512-GlsNBWiFQFCVi9QVSx7f5AgMeLxe9YCCs5PuP2O2LdjDAA8Jh9eX7lA1Jq/xdXw3Wb3hyvlFNfZIfcRetSzYcA==}
    engines: {node: ^14.15.0 || ^16.10.0 || >=18.0.0}

  '@jest/schemas@29.6.3':
    resolution: {integrity: sha512-mo5j5X+jIZmJQveBKeS/clAueipV7KgiX1vMgCxam1RNYiqE1w62n0/tJJnHtjW8ZHcQco5gY85jA3mi0L+nSA==}
    engines: {node: ^14.15.0 || ^16.10.0 || >=18.0.0}

  '@jest/types@29.6.3':
    resolution: {integrity: sha512-u3UPsIilWKOM3F9CXtrG8LEJmNxwoCQC/XVj4IKYXvvpx7QIi/Kg1LI5uDmDpKlac62NUtX7eLjRh+jVZcLOzw==}
    engines: {node: ^14.15.0 || ^16.10.0 || >=18.0.0}

  '@jridgewell/gen-mapping@0.3.8':
    resolution: {integrity: sha512-imAbBGkb+ebQyxKgzv5Hu2nmROxoDOXHh80evxdoXNOrvAnVx7zimzc1Oo5h9RlfV4vPXaE2iM5pOFbvOCClWA==}
    engines: {node: '>=6.0.0'}

  '@jridgewell/resolve-uri@3.1.2':
    resolution: {integrity: sha512-bRISgCIjP20/tbWSPWMEi54QVPRZExkuD9lJL+UIxUKtwVJA8wW1Trb1jMs1RFXo1CBTNZ/5hpC9QvmKWdopKw==}
    engines: {node: '>=6.0.0'}

  '@jridgewell/set-array@1.2.1':
    resolution: {integrity: sha512-R8gLRTZeyp03ymzP/6Lil/28tGeGEzhx1q2k703KGWRAI1VdvPIXdG70VJc2pAMw3NA6JKL5hhFu1sJX0Mnn/A==}
    engines: {node: '>=6.0.0'}

  '@jridgewell/source-map@0.3.6':
    resolution: {integrity: sha512-1ZJTZebgqllO79ue2bm3rIGud/bOe0pP5BjSRCRxxYkEZS8STV7zN84UBbiYu7jy+eCKSnVIUgoWWE/tt+shMQ==}

  '@jridgewell/sourcemap-codec@1.5.0':
    resolution: {integrity: sha512-gv3ZRaISU3fjPAgNsriBRqGWQL6quFx04YMPW/zD8XMLsU32mhCCbfbO6KZFLjvYpCZ8zyDEgqsgf+PwPaM7GQ==}

  '@jridgewell/trace-mapping@0.3.25':
    resolution: {integrity: sha512-vNk6aEwybGtawWmy/PzwnGDOjCkLWSD2wqvjGGAgOAwCGWySYXfYoxt00IJkTF+8Lb57DwOb3Aa0o9CApepiYQ==}

  '@jridgewell/trace-mapping@0.3.9':
    resolution: {integrity: sha512-3Belt6tdc8bPgAtbcmdtNJlirVoTmEb5e2gC94PnkwEW9jI6CAHUeoG85tjWP5WquqfavoMtMwiG4P926ZKKuQ==}

  '@jsonjoy.com/base64@1.1.2':
    resolution: {integrity: sha512-q6XAnWQDIMA3+FTiOYajoYqySkO+JSat0ytXGSuRdq9uXE7o92gzuQwQM14xaCRlBLGq3v5miDGC4vkVTn54xA==}
    engines: {node: '>=10.0'}
    peerDependencies:
      tslib: '2'

  '@jsonjoy.com/json-pack@1.2.0':
    resolution: {integrity: sha512-io1zEbbYcElht3tdlqEOFxZ0dMTYrHz9iMf0gqn1pPjZFTCgM5R4R5IMA20Chb2UPYYsxjzs8CgZ7Nb5n2K2rA==}
    engines: {node: '>=10.0'}
    peerDependencies:
      tslib: '2'

  '@jsonjoy.com/util@1.5.0':
    resolution: {integrity: sha512-ojoNsrIuPI9g6o8UxhraZQSyF2ByJanAY4cTFbc8Mf2AXEF4aQRGY1dJxyJpuyav8r9FGflEt/Ff3u5Nt6YMPA==}
    engines: {node: '>=10.0'}
    peerDependencies:
      tslib: '2'

  '@kurkle/color@0.3.4':
    resolution: {integrity: sha512-M5UknZPHRu3DEDWoipU6sE8PdkZ6Z/S+v4dD+Ke8IaNlpdSQah50lz1KtcFBa2vsdOnwbbnxJwVM4wty6udA5w==}

  '@leichtgewicht/ip-codec@2.0.5':
    resolution: {integrity: sha512-Vo+PSpZG2/fmgmiNzYK9qWRh8h/CHrwD0mo1h1DzL4yzHNSfWYujGTYsWGreD000gcgmZ7K4Ys6Tx9TxtsKdDw==}

  '@protobufjs/aspromise@1.1.2':
    resolution: {integrity: sha512-j+gKExEuLmKwvz3OgROXtrJ2UG2x8Ch2YZUxahh+s1F2HZ+wAceUNLkvy6zKCPVRkU++ZWQrdxsUeQXmcg4uoQ==}
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

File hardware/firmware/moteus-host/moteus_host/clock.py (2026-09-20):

"""Move an attached arrow like a twelve-tick, one-minute clock."""

from __future__ import annotations

import argparse
import asyncio
import json
import math
import time
from collections.abc import Sequence
from pathlib import Path
from typing import Any


TICK_SECONDS = 5.0
TICKS_PER_REVOLUTION = 12
COMMAND_PERIOD_SECONDS = 0.02
WATCHDOG_SECONDS = 0.10
MOVE_TIMEOUT_SECONDS = 10.0
POSITION_TOLERANCE_REV = 0.005
VELOCITY_TOLERANCE_REV_S = 0.02
SETTLED_SAMPLES = 5
CALIBRATION_PATH = Path(__file__).resolve().parents[1] / ".minute-clock-zero.json"


def build_parser() -> argparse.ArgumentParser:
    parser = argparse.ArgumentParser(
        description="Advance a moteus-driven arrow by 30 degrees every 5 seconds."
    )
    parser.add_argument("--id", type=int, default=1, help="moteus CAN ID (default: 1)")
    parser.add_argument(
        "--calibrate",
        action="store_true",
        help="keep the motor stopped while the arrow is aligned to 12 o'clock",
    )
    parser.add_argument(
        "--clockwise-sign",
        type=int,
        choices=(-1, 1),
        help="override the saved clockwise position sign",
    )
    parser.add_argument(
        "--max-torque",
        type=float,
        default=0.10,
        help="command torque ceiling in Nm (default: 0.10)",
    )
    parser.add_argument(
        "--velocity-limit",
        type=float,
        default=0.25,
        help="motion velocity ceiling in revolutions/s (default: 0.25)",
    )
    parser.add_argument(
        "--accel-limit",
        type=float,
        default=0.50,
        help="motion acceleration ceiling in revolutions/s^2 (default: 0.50)",
    )
    return parser


def load_calibration(controller_id: int) -> dict[str, Any]:
    if not CALIBRATION_PATH.exists():
        raise RuntimeError(
            f"No clock zero stored in {CALIBRATION_PATH}. "
            "Run once with --calibrate."
        )

    try:
        document = json.loads(CALIBRATION_PATH.read_text())
        calibration = document["controllers"][str(controller_id)]
        upright_position = float(calibration["upright_position_modulo"])
        clockwise_sign = int(calibration["clockwise_sign"])
    except (KeyError, TypeError, ValueError, json.JSONDecodeError) as exc:
        raise RuntimeError(
            f"Invalid clock calibration for moteus {controller_id} in "
            f"{CALIBRATION_PATH}; run with --calibrate to replace it."
        ) from exc

    if not 0.0 <= upright_position < 1.0 or clockwise_sign not in (-1, 1):
        raise RuntimeError(
            f"Invalid clock calibration for moteus {controller_id} in "
            f"{CALIBRATION_PATH}; run with --calibrate to replace it."
        )

    return {
        "upright_position_modulo": upright_position,
        "clockwise_sign": clockwise_sign,
    }


def save_calibration(
    controller_id: int, upright_position: float, clockwise_sign: int
) -> None:
    document: dict[str, Any] = {"format_version": 1, "controllers": {}}
    if CALIBRATION_PATH.exists():
        try:
            existing = json.loads(CALIBRATION_PATH.read_text())
            if (
                existing.get("format_version") == 1
                and isinstance(existing.get("controllers"), dict)
            ):
                document = existing
        except (AttributeError, json.JSONDecodeError):
            pass

    document["controllers"][str(controller_id)] = {
        "upright_position_modulo": upright_position % 1.0,
        "clockwise_sign": clockwise_sign,
    }
    temporary_path = CALIBRATION_PATH.with_suffix(".tmp")
    temporary_path.write_text(json.dumps(document, indent=2) + "\n")
    temporary_path.replace(CALIBRATION_PATH)


def nearest_equivalent_position(current: float, position_modulo: float) -> float:
    """Return the equivalent single-turn angle nearest to current."""
    turns = math.floor(current - position_modulo + 0.5)
    return position_modulo + turns


async def set_position(controller: Any, target: float, args: argparse.Namespace) -> Any:
    return await controller.set_position(
        position=target,
        velocity=0.0,
        maximum_torque=args.max_torque,
        velocity_limit=args.velocity_limit,
        accel_limit=args.accel_limit,
        watchdog_timeout=WATCHDOG_SECONDS,
        query=True,
    )


async def move_to_upright(
    controller: Any, target: float, args: argparse.Namespace, moteus: Any
) -> None:
    deadline = time.monotonic() + MOVE_TIMEOUT_SECONDS
    settled_samples = 0

    while time.monotonic() < deadline:
        state = await set_position(controller, target, args)
        fault = state.values.get(moteus.Register.FAULT, 0)
        if fault:
            raise RuntimeError(f"moteus reported fault {fault}")

        position = state.values[moteus.Register.POSITION]
        velocity = state.values[moteus.Register.VELOCITY]
        if (
            abs(position - target) <= POSITION_TOLERANCE_REV
            and abs(velocity) <= VELOCITY_TOLERANCE_REV_S
        ):
            settled_samples += 1
            if settled_samples >= SETTLED_SAMPLES:
                return
        else:
            settled_samples = 0

        await asyncio.sleep(COMMAND_PERIOD_SECONDS)

    raise RuntimeError("Timed out while moving the arrow to 12 o'clock")
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

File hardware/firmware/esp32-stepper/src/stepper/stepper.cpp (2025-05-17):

#include <Arduino.h>

#include "stepper.h"

int getTicksPerPulse(float velocity, int32_t ticksPerSecond, uint32_t pulsesPerRevolution, uint32_t pulseWidth) {
  if (abs(velocity) < 1e-3) {
    return UINT32_MAX;
  } else {
    return (uint32_t)(TWO_PI * ticksPerSecond / (abs(velocity) * pulsesPerRevolution)) - pulseWidth;
  }  
}

Stepper::Stepper(int enablePin, int dirPin, int stepPin, uint32_t ticksPerSecond, uint32_t pulsesPerRevolution, uint32_t pulseWidth) {
  this->enablePin = enablePin;
  this->dirPin = dirPin;
  this->stepPin = stepPin;
  this->ticksPerSecond = ticksPerSecond;
  this->pulsesPerRevolution = pulsesPerRevolution;
  this->pulseWidth = pulseWidth;  
}

void Stepper::init() {
  pinMode(enablePin, OUTPUT);
  pinMode(dirPin, OUTPUT);
  pinMode(stepPin, OUTPUT);
  digitalWrite(stepPin, LOW);
  
  this->currentTick = 0;
}

void Stepper::setEnabled(bool enabled) {
  digitalWrite(enablePin, enabled ? LOW : HIGH);
}

void Stepper::setVelocity(float velocity) {
  ticksPerPulse = getTicksPerPulse(velocity, ticksPerSecond, pulsesPerRevolution, pulseWidth);
  digitalWrite(dirPin, velocity > 0 ? HIGH : LOW);
}

void Stepper::tick() {
  if (currentTick >= ticksPerPulse) {
    currentTick = 0;
  }
  if (currentTick == 0) {
    digitalWrite(stepPin, HIGH);
  } else if (currentTick == pulseWidth) {    
    digitalWrite(stepPin, LOW);
  }
  currentTick++; 
}

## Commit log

2025-04-15 review the trainging flow
2025-05-17 stepper enabled
2025-05-20 IMU got back to lifE
2025-09-07 use Klaman filter to calculate to roll
2025-09-14 fixed rate executor added
    [main.cpp]
2025-09-19 MPU connected to a stepper
2025-10-05 calculate angle at the top correctly
    [MPU.cpp]
2025-10-20 stabilizing with LQR & PID
2025-10-22 LQR regulator implemented
2026-09-04 Restructure repository by concept
    - software/{sim,rl,web}: runs on a laptop; hardware/{firmware,cad,tools}: runs on the device
    - rl: split into fip_env (env), train, export, models; drop non-FIP examples
    - models consolidated in software/rl/models, web build copies the ONNX from there
    - docs/: physics, hardware, drl notes and reference papers moved in from the vault
    - ROADMAP.md, LOG.md and root README carry the process (DoD, phases, log)
2026-09-04 Phase 0: torque budget with moteus conventions, swing-up gate, r4.11 decision
    - Kt = 8.27/Kv per moteus firmware (mj5208: 0.0251 Nm/A, c1 peak 0.50 Nm)
    - voltage-circle torque-speed envelope; no-load 2740 rpm at 12 V
    - phase0_swingup: energy pumping + LQR catch, required momentum 0.19-0.45 Nms,
    wheel window I_w >= 0.0015-0.0022 kg m2, recommend 0.003
    - battery on the pivot axis; driver decision moteus r4.11
    - phase0.toml with per-block provenance, 15 tests, docs/log/roadmap updated
2026-09-04 CAD: OpenSCAD wheel, rod and table-clamp stand with tests and mass model
    - docs/hardware/cad-spec.md: approved design (rotating axle in stand
    bearings, table-edge C-clamp, Ø280 four-quadrant wheel, IMU on pendulum,
    battery and RPi on the axle)
    - hardware/cad: params, lib, wheel, rod, stand, assembly, interference
    check, Makefile, stl_props (volume/centroid/inertia from STL), mass model,
    23 tests; renders: quadrant 27.7 g, beam 64 g, flange 42 g, stand 152 g
    - mass model -> software/sim/phase0.toml: m_t 0.776 kg, l_c 0.146 m,
    G 1.11 Nm, I_w 0.0027; Phase 0 gates still pass (capped swing-up 24/24)
    - plan moved to .claude/plans/, convention added to CLAUDE.md
    - includes docs/drl/mode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
    [assembly.scad, check.scad, lib.scad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]
2026-09-11 learning MuJoCo
    [scene.xml]
2026-09-12 intercation with the model
    [scene.xml]
2026-09-12 sim: add MuJoCo flywheel pendulum exercises
    [scene.xml, wheel.stl]
2026-09-12 LQR stabilization
    [scene.xml, wheel.stl]
2026-10-25 PNDLM-8: torque-pulse response timing pilot, report and tooling
    - bench response-timing experiment with quiet baseline, watchdog-bounded
    pulses, timeout-mode override/restore; fixes found on hardware (transport
    open timeout, conf get without OK, Stream flow-control probe, stop readback)
    - offline analyzers for position-step and response-timing runs with tests
    - report docs/hardware/desk-stand-torque-pulse-timing.md: 7-13 ms detection
    bound at 0.01/0.015/0.02 Nm, derived JSON with SHA-256 provenance
    - spec, feasibility delay threshold, log, glossary and bench.toml updated
    - backlog moved to YouTrack PNDLM; MCP config and docs updated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
2026-10-25 torque constant analyzer
2026-10-26 PNDLM-9: static torque constant measured, anticogging identified
    Kt = 0.0244 ± 0.0005 Nm/A per commanded ampere in the 2–6 A linear region,
    both directions within 0.3 %, 87.5 % of the firmware 8.27/Kv. The constant
    −0.25 A between measured and commanded current is the anticogging
    feedforward (matches the cogging table at the rotor position within 0.01 A),
    not a current shortfall. With a pre-hold the current loop reaches 95 % of a
    step by the first host sample (4.4 ms): no torque rate limit within one
    control sample. Results and simulator-facing assumptions in the fixture
    spec §9–10, data in docs/hardware/measurements/2026-10-26-*.json.
    Bench tool: excursion origin re-anchored per pl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
2026-10-27 PNDLM-10: stator pattern verified against the mjbots mj5208 drawing
    The 4x M3 stator holes sit on a Ø25 bolt circle (rev. 3, 2025-07-26), not
    on a 25 mm square as assumed. stator_pitch -> stator_bc_d, motor_flange
    holes laid out on the circle; cad-spec §1 and parameter table updated,
    "to verify" removed; log entry added.
2026-10-28 feat(bench): coast-down analysis and analyze dispatch
    Windowed -I*alpha loss points, 1 rev/s loss map, a+b*w+c*w^2 fit with
    standard errors, plateau kt*i cross-check and effective inertia from the
    acceleration trials (loss-corrected). summarize.analyze now dispatches
    on the run's experiment field.
2026-10-28 feat(bench): coast-down experiment and CLI
    Speed-ladder free coast-downs and --accelerate torque steps on the test
    disc. Volatile overrides (timeout_mode 0, position bounds NaN,
    servo.max_velocity) with readback and restore in finally; GO gate per
    step; a safety stop or Ctrl-C sends the stop and then waits for
    standstill before exiting. --ladder and --direction overrides, --dry-run.
2026-10-28 fix(bench): coast-down cleanup survives Ctrl-C and lost replies
    Treat task cancellation (what asyncio.run does on SIGINT) as an
    interruption, swallow a second Ctrl-C during the standstill wait, retry
    the cleanup stop and tolerate lost query replies. Require position mode
    during commanded phases so a watchdog trip is a safety stop, not data.
    Velocity commands use kp_scale 0 (no ramp-end brake) and the flux brake
    is set to 27 V for the run so regeneration never reaches the supply.
2026-10-28 fix(bench): coast-down analysis recovers the rotor inertia and accepts partial runs
    Non-overlapping index-based windows (honest standard errors, O(N)).
    With acceleration trials the total rotating inertia comes from matched
    speeds, kt*i / (alpha_accel + |alpha_coast|), with no loss model, and
    scales the loss map; the disc record is the fallback. Safety-stopped and
    interrupted runs analyze their completed steps. Plateau rows carry the
    coast fit at the same speed.
2026-10-28 PNDLM-11: test disc, rotor pattern gauge and inertia record
    Ø150 three-spoke test disc (98.6 g rendered, 93.9 g printed,
    I_z 0.000354 kg·m² with screws) and a 2 mm fit gauge that confirmed the
    Ø17 rotor pattern; rotor_bc_d = 17. Measurement record with rendered,
    printed and mounting values; bifilar inertia measurement note.
2026-10-28 fix(bench): flux brake override per firmware key; honest cleanup message
    2025 firmware has servo.flux_brake_margin_voltage (threshold =
    max_voltage - margin) instead of flux_brake_min_voltage; pick whichever
    exists and stop before motion if neither does. The "disconnect power"
    line is printed only when motion was actually commanded.
2026-10-28 fix(bench): coast ends only after the speed settles below the threshold
    Seen on hardware at 15-20 rpm: the encoder velocity jitters about
    ±0.05 rev/s around the 0.2 rev/s threshold, so a single sample ended the
    coast at once and a single blip refused the next step. The coast, the
    standstill wait and a new preflight wait now require coast_settle_s
    (0.25 s) continuously below the threshold.
2026-10-28 fix(bench): tolerate the firmware enable sequence at the start of a step
    Position mode is required 50 ms after the first command of a step, not
    after two samples of each phase: at 30 rpm the spin-up ended on its
    first sample and the plateau saw modes 2 and 3 from the enable
    sequence. Low ladder steps now ramp to within 30 % of the target before
    the plateau, and the preflight wait no longer prints "coasting: 0 rpm".
2026-10-28 fix(bench): spin-up tolerance scales with the target speed
    The kd-only velocity loop settles 10-25 % below the target under load
    (26 rpm at the 30 rpm step). Reached = within max(0.5 rev/s, 10 %),
    capped at 30 % so low steps still ramp; the plateau records the true
    speed, so the analysis is unaffected.
2026-11-01 rail anchor added
2026-11-01 PNDLM-11: rotating losses to 3000 rpm both directions, effective inertia, measurement record
2026-11-01 feat(bench): torque-speed configuration and 70 rev/s Tier B cap
2026-11-01 feat(bench): torque-speed step monitor, planning and records
2026-11-01 feat(bench): torque-speed experiment and CLI
2026-11-01 fix(bench): torque-speed top step keeps margin under the Tier B torque and current caps
2026-11-01 feat(bench): torque-speed per-run analysis
2026-11-01 feat(bench): envelope fit across torque-speed runs
2026-11-01 docs: torque-speed bench usage, spec status and log
2026-11-01 fix(bench): torque-speed sag floor, raw-row reference, r_max from no-load and knees with K_t term, measured bus
    - sag_stop_v 0.8: the stop sits one 0.1 V telemetry step above the 10 V floor;
    validate and check_bus (also with --allow-any-bus) enforce it
    - low-speed reference from one fit over the raw band rows, so a 0.18 Nm step
    at 11 V keeps a reference and a knee
    - envelope: r_max pooled from saturated no-load points and knees at their
    measured bus, per-group means, K_t +-3 % term in the K_t-derived se
    - knee carries the measured bus; sagging hold rows are dropped from no-load
    - tests for the hold_end sag path and the knee fallback; spec, README and
    test-disc 4000 rpm rating table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
2026-11-04 fix(bench): torque-speed limit codes, speed windows, sag flag at the stop level, 0.15 Nm top step
    - moteus fault register 96..103 in a control mode marks the active limit
    (98 = bus voltage), not a fault: stop only in mode 1 or on codes below 96
    - analysis windows by speed (1.5 rev/s, >= 10 rows) instead of 0.25 s; the
    knee is the last window above 90 % and the next one, so a noisy dip is
    not a knee
    - supply-limited flag at sag_stop_v; sag_threshold_v removed (the lead drop
    at the step currents is not a supply sag)
    - default torques 0.05/0.10/0.15 Nm: 0.18 tripped the 0.20 Nm cap on noise
2026-11-04 docs: torque-speed measurement record and log (PNDLM-12)
    248.3 ± 1.0 rpm/V over 11.0-14.8 V, r_max = 1.00 with Kv 339 from the
    measured K_t; 16.0 V velocity-capped at the host stop, 16.8 V not run.
2026-11-08 docs: response-delay article draft, figures and Phase 0 timing re-run (PNDLM-8)
    - docs/content: article draft on actuator command delay with figures A
    (one torque pulse) and B (delay scale vs fall time)
    - software/sim: plot_response_delay.py renders both figures from
    repository data
    - docs/hardware/measurements: column extract of the 0.02 Nm run telemetry
    for figure A
    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
2026-11-08 docs: anticogging explains the PNDLM-8 current shortfall, not the enable sequence
    - motor-torque-fixture §9.3: the controller was already in mode 10 before
    every PNDLM-8 pulse, so the ~15 ms enable sequence does not apply. The
    shortfall is on positive pulses only; subtracting the interpolated
    cogging_dq_comp term removes the sign asymmetry and leaves a gap within
    current noise. The same table matches the non-zero rest current.
    - desk-stand-torque-pulse-timing: pointers to the correction
    - article draft: section 5 rewritten accordingly
2026-11-09 PNDLM-11: plateau re-analysis, rotating losses in the Phase 0 LQR sim
    - bench analyze: plateau loss from |mean i_q|, not mean |i_q|; the
    ripple crosses zero and the per-sample magnitude read 4-14 % high.
    Re-analysed record: gap -2.9..+8.3 %, superseded values kept.
    - coast-down spec section 8: documented deviations, Coulomb term
    assumption 3-7 mNm for the final assembly, stick-slip sim check
    - software/sim: [losses] block in phase0.toml, loss torque between
    rotor and body on relative speed, phase0-control --losses
    - log entry 08.11.2026
2026-11-09 docs: torque-speed article (PNDLM-12), docs/content -> docs/articles with frontmatter
    - New draft 2026-11-04-torque-speed-draft.md with two figures rendered by
    software/sim/app/plot_torque_speed.py (no-load speed vs bus, torque vs
    speed at 12 V, voltage-circle vectors).
    - Rename docs/content to docs/articles and update references.
    - Article headers become YAML frontmatter; drop the publication-platform note.
2026-11-09 PNDLM-14: measured motor inputs in phase0.toml, re-run Phase 0 checks
    K_t 0.0244 (PNDLM-9) as input, Kv 339 derived; r_max 1.00 (PNDLM-12);
    R/L from controller calibration; rotor inertia added to the flywheel;
    thermal model marked as assumption with hot R and hot K_t (PNDLM-13).
